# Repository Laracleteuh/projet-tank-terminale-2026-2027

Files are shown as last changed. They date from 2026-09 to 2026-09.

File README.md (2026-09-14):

# projet-tank-terminale-2026-2027 ###

Repo GitHub pour le projet de Tank RC des Terminales spécialités sciences de l'ingénieur. Contenu Open Source, et maintenu jusqu'en juillet 2027

### Configuration Requise ###

Ce projet est basé autour de l'Arduino Mega 2560 programmé via VS Code et son extension PlatformIO.
Sur chaque release un fichier .zip a build et un .hex pouvant être uploadé directement sera disponible.
Le fichier d'environnement platformio.ini est publié dans son dossier /PlatformIO/

### Tank OS ###

La dernière version en date de TankOS est TankOS 1.
[Lien vers la dernière release de TankOS](https://github.com/Laracleteuh/projet-tank-terminale-2026-2027/releases/tag/TankOS1)

*La documentation technique se trouve dans Manuel Utilisateur / Logiciel / TankOS 1.html - .pdf*

### PCB Custom ###

Ce projet contient quelques cartes électroniques faites sur mesure. Les fichiers de celles-ci seront disponibles plus tard dans l'année, quand leur design sera validé et fonctionnel.
Ces designs ont étés fait sur KiCAD.

### Python Scripts ###

Ce projet contient un dossier réservé à des scripts python. Ils sont fait maison et permettent de calculer des caractéristiques en rapport avec les moteurs plus facilement, n'hesitez pas à vous en servir si besoin ;). Pour moins se casser la tête pour des valeurs par défaut, dans la première input, tapez "def" pour charger les valeurs par défaut du programme. Elles seront mises à jour si jamais elles changent au cours du projet.

### MatLab ###

Ce projet contient un dossier réservé aux modèles MatLab et aux calculs. Dans celui-ci vous pourrez trouver le(s) modèle(s) de simulation des moteurs, et la fiche de calcul qui justifie CHAQUE valeur de MatLab (autre que celle qu'on peut trouver dans les docs techniques, vous pouvez chercher quand même, là c'est que les calculs)

### User Manuals ###

Ce projet contient un dossier réservé aux manuels utilisateurs. Ces manuels seront répartis dans des dossiers selon le type d'élément qu'ils présentent (PCB par exemple)

### Feuilles de Calcul ###

Ce projet contient un dossier réservé aux feuilles de calculs pour le tank. Utile si besoin. (Feuilles manuscrites)

### Nom des versions ###

Deux types de firmware sont actuellement utilisés : 
  - Les _PUBLIC_PREVIEW (PR) -> firmware non-testés sur du materiel réel, soumis à des erreurs
  - Les _PUBLIC_RELEASE (REL) -> firmware testé sur du materiel et certifié sans erreur, soumis à des ajouts de fonctionnalité dans le futur

Chaque mise à jour est présentée sous la forme suivante : 20XX.Y_TYPE

20XX -> correspond à l'année d'écriture du firmware

.Y -> correspond à la version du firmware

_TYPE -> soit _PUBLIC_PREVIEW ou _PUBLIC_RELEASE

---
### Licence ###

Ce projet est distribué sous licence MIT pour le code. Les schémas électroniques et fichiers PCB sont mis à disposition sous licence CERN-OHL-P v2.

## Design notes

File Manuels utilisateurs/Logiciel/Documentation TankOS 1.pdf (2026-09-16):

# Documentation TankOS1

### Groupe Spécialité Sciences de l’Ingénieur 16 Septembre 2026

Firmware de contrôle pour plateforme chenillée radiocommandée

Projet Tank Terminale, Spécialité Sciences de l’Ingénieur, session 2026/2027 — Version 1 — Carte cible Arduino Mega 2560 (ATmega2560)

### Sommaire

### Introduction

### 1. Présentation générale

TankOS est le firmware embarqué pilotant une plateforme chenillée radiocommandée à deux moteurs de traction et une tourelle motorisée équipée d’un système d’armement simulé (ESC double). Le firmware est écrit en C++ pour l’environnement Arduino, compilé et déployé via PlatformIO, et s’exécute sur une carte Arduino Mega 2560 basée sur le microcontrôleur ATmega2560 (8 bits, 16 MHz, 8 Ko de SRAM, 256 Ko de mémoire programme).

Le système repose sur un noyau temps réel FreeRTOS (portage AVR de la bibliothèque feilipu/FreeRTOS) et organise le traitement en cinq tâches concurrentes ordonnancées par priorité. Cette architecture remplace une structure séquentielle classique de type loop() et garantit que les fonctions critiques de sécurité (perte de liaison radio, surintensité, décharge batterie) sont exécutées avec une latence bornée, indépendamment de la charge des autres sous-systèmes.

Les fonctions principales assurées par le firmware sont les suivantes :
- Pilotage différentiel de la traction par relais et potentiomètres numériques SPI
- Pilotage de la tourelle : élévation et rotation par servomoteurs, activation de deux contrôleurs de vitesse électroniques (ESC)
- Réception de dix voies de la radiocommande par capture d’impulsions PWM en interruption
- Supervision de deux batteries (châssis et tourelle) et d’un capteur de courant, avec bridage automatique de la vitesse et alertes
- Coupure matérielle de l’alimentation moteur en cas de défaillance (MOSFET de puissance piloté logiciellement)
- Contrôle d’accès par badge RFID pour déverrouiller les commandes sensibles
- Interface de commande textuelle disponible simultanément sur liaison série USB et sur module Bluetooth HM-10
- Régulation thermique par ventilateur piloté en PWM matériel haute fréquence

TankOS 1 — Documentation technique — Projet Tank Terminale, Spécialité SI 2026/2027

### 2. Architecture matérielle

L’ensemble du brochage est centralisé dans le fichier config.h, seul point de référence pour toute modification physique du câblage. Les sous-systèmes matériels sont décrits ci-dessous ; le détail exhaustif des broches figure en annexe.

### 2.1 Chaîne de traction

Chaque moteur de traction est commandé par un ensemble de relais montés sur une carte pilote MDRVCT60A002M. La direction (avant/arrière) de chaque moteur est sélectionnée par une paire de relais dédiés, et deux relais supplémentaires assurent la coupure générale de l’alimentation de chaque côté (fonction de sécurité indépendante de la direction). La vitesse est réglée par un potentiomètre numérique SPI MCP41100 par moteur, adressé par une broche CS dédiée (42 pour le moteur gauche, 43 pour le moteur droit), le bus SPI (SCK/MOSI/MISO sur les broches matérielles 52/51/50) étant partagé avec le lecteur RFID.

### 2.2 Tourelle

La tourelle intègre trois servomoteurs analogiques pour le mouvement d’élévation et la rotation (broches 2, 3 et 6 pilotées en parallèle) et deux ESC pour l’armement (broches 4 et 5, pilotage en largeur d’impulsion de 1000 à 2000 microsecondes).

### 2.3 Réception radiocommande

Une radiocommande de type huit voies transmet des signaux PWM captés par interruption logicielle sur changement d’état (bibliothèque enableInterrupt). Les voies exploitées couvrent la direction et la vitesse de traction, l’orientation et l’élévation de la tourelle, l’armement, la vitesse de rampe (VRB) et deux interrupteurs auxiliaires (SWC, SWD). La capture est réalisée dans ISR.cpp, fichier isolé du reste du firmware car il gère les temporisations critiques en contexte d’interruption.

### 2.4 Lecteur RFID

Le contrôle d’accès admin repose sur un lecteur RC522 en liaison SPI, avec sélection sur la broche 41 et réinitialisation sur la broche 40. Sur Mega, le bus SPI matériel est situé sur les broches 50/51/52 (contrairement à un Uno où il se trouve sur 11/12/13), et des résistances série de 330 ohms sont insérées sur SCK et MOSI pour la compatibilité de niveaux logiques 5V du module.

### 2.5 Liaison Bluetooth

Un module HM-10 est connecté sur Serial1 à 9600 bauds et fournit une interface de commande sans fil identique à la liaison série USB. Une broche BRK (37) permet de forcer une rupture de connexion Bluetooth de façon logicielle.

### 2.6 Capteurs et actionneurs auxiliaires

La température est relevée par un capteur I2C MCP9808. Deux ponts diviseurs analogiques mesurent la tension des batteries châssis (A1) et tourelle (A2), un capteur à effet Hall (type ACS) mesure le courant consommé (A0). Un ventilateur est commandé en modulation de largeur d’impulsion matérielle à 25 kHz par configuration directe du timer 2 (broche 9). Une LED RGB de statut (broches 46 à 49) restitue l’état global du système.

### 2.7 Sécurité matérielle

Un transistor MOSFET canal P (FQP27P06) commandé sur la broche 32 permet la coupure matérielle de l’alimentation de puissance de la chaîne de traction, indépendamment de l’état des relais de direction, en complément de la logique de sécurité logicielle.

### 3. Architecture logicielle et ordonnancement FreeRTOS

Le firmware utilise le portage AVR de FreeRTOS (feilipu/FreeRTOS) afin de garantir un ordonnancement préemptif par priorité. Cinq tâches sont créées au démarrage, chacune encapsulant une boucle infinie rythmée par vTaskDelay(), ce qui libère le processeur pour les tâches de priorité inférieure ou égale pendant l’attente.

Tâche | Priorité | Période | Responsabilité
TaskSafety | 4 (la plus haute) | 20 ms | Détection de perte de liaison radio, calcul du facteur de bridage batterie, coupure de l’alimentation trac-tion, gestion de la LED de statut
TaskTraction | 3 | 34 ms | Lecture des voies radio et application des consignes de vitesse/direction à la chaîne de traction
TaskTourelle | 3 | 34 ms | Élévation, rotation et armement de la tourelle
TaskCommunication | 2 | 20 ms | Traitement des commandes série/Bluetooth, gestion des ventilateurs, télémétrie périodique
TaskAdmin | 1 (la plus basse) | 50 ms | Scrutation du lecteur RFID et gestion du verrouillage admin

La priorité de TaskSafety est volontairement maximale : elle doit pouvoir préempter toute autre tâche afin de garantir la coupure immédiate de la traction et de la tourelle en cas de perte de signal, quelle que soit la charge des autres modules.

### 3.1 Synchronisation par mutex

Deux sémaphores mutex, déclarés globalement dans config.h et instanciés dans main.cpp, protègent les ressources partagées entre tâches :
- spiMutex : protège l’accès exclusif au bus SPI matériel, partagé entre le lecteur RC522 (admin.cpp) et les potentiomètres numériques MCP41100 (traction.cpp). La totalité d’une transaction (sélection du composant, transfert des octets, désélection) est encadrée par la prise et la libération du mutex, afin de garantir son atomicité.
- stateMutex : protège l’état partagé calculé par TaskSafety (indicateur de failsafe actif, facteur de bridage de vitesse)
et consommé par TaskTraction et TaskTourelle.

Les prises de mutex sont systématiquement bornées dans le temps (pdMS_TO_TICKS(5)) : en cas d’indisponibilité, la tâche appelante renonce à l’opération pour le cycle courant plutôt que de bloquer indéfiniment, préservant ainsi le respect des échéances temporelles de l’ordonnanceur.

### 3.2 Communication inter-tâches

Les données de la radiocommande sont exposées par getRecepteurData(), qui recopie sous section critique (taskENTER_CRITICAL() / taskEXIT_CRITICAL()) les variables volatiles renseignées par les routines d’interruption vers une structure RcData locale à chaque tâche appelante. Cette structure regroupe les huit canaux : axes de traction, axes de tourelle, interrupteurs SWC/SWD, potentiomètres VRA/VRB.

### 3.3 Point d’entrée et supervision

La fonction setup() initialise séquentiellement chaque module matériel, crée les mutex, instancie les cinq tâches via xTaskCreate() en vérifiant systématiquement leur code de retour, puis démarre l’ordonnanceur via vTaskStartScheduler(). La fonction loop() Arduino reste vide, le contrôle étant entièrement cédé au noyau FreeRTOS. Un hook vApplicationStackOverflowHook() est enregistré pour signaler sur le port série tout dépassement de pile d’une tâche et figer volontairement le système, ce comportement étant préférable à une corruption mémoire silencieuse.

### 4. Module Traction

Le module traction.cpp implémente une machine à états par moteur (structure Motor), avec trois états : IDLE (moteur arrêté), RUNNING (moteur en mouvement dans une direction donnée) et SWITCHING (phase transitoire lors d’une inversion de direction). Un changement direct de sens de marche sans passage par un arrêt intermédiaire de 200 millisecondes est proscrit afin de protéger l’électronique de puissance et les moteurs des courants d’appel liés à une inversion brutale.

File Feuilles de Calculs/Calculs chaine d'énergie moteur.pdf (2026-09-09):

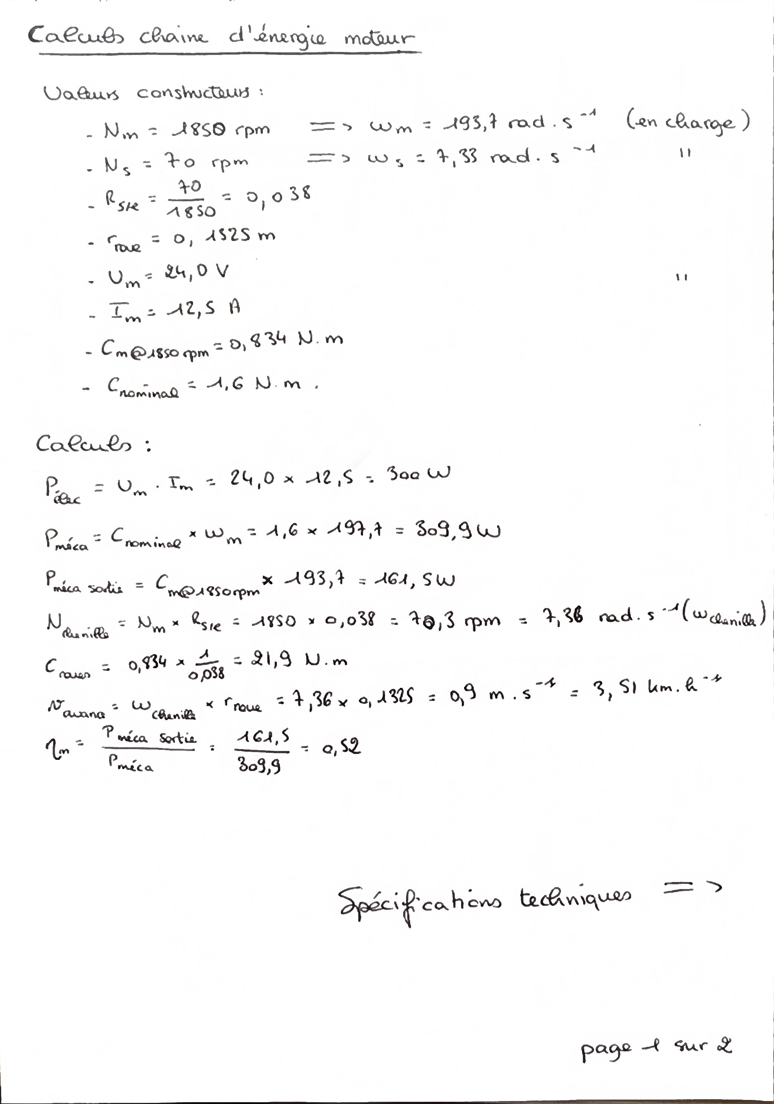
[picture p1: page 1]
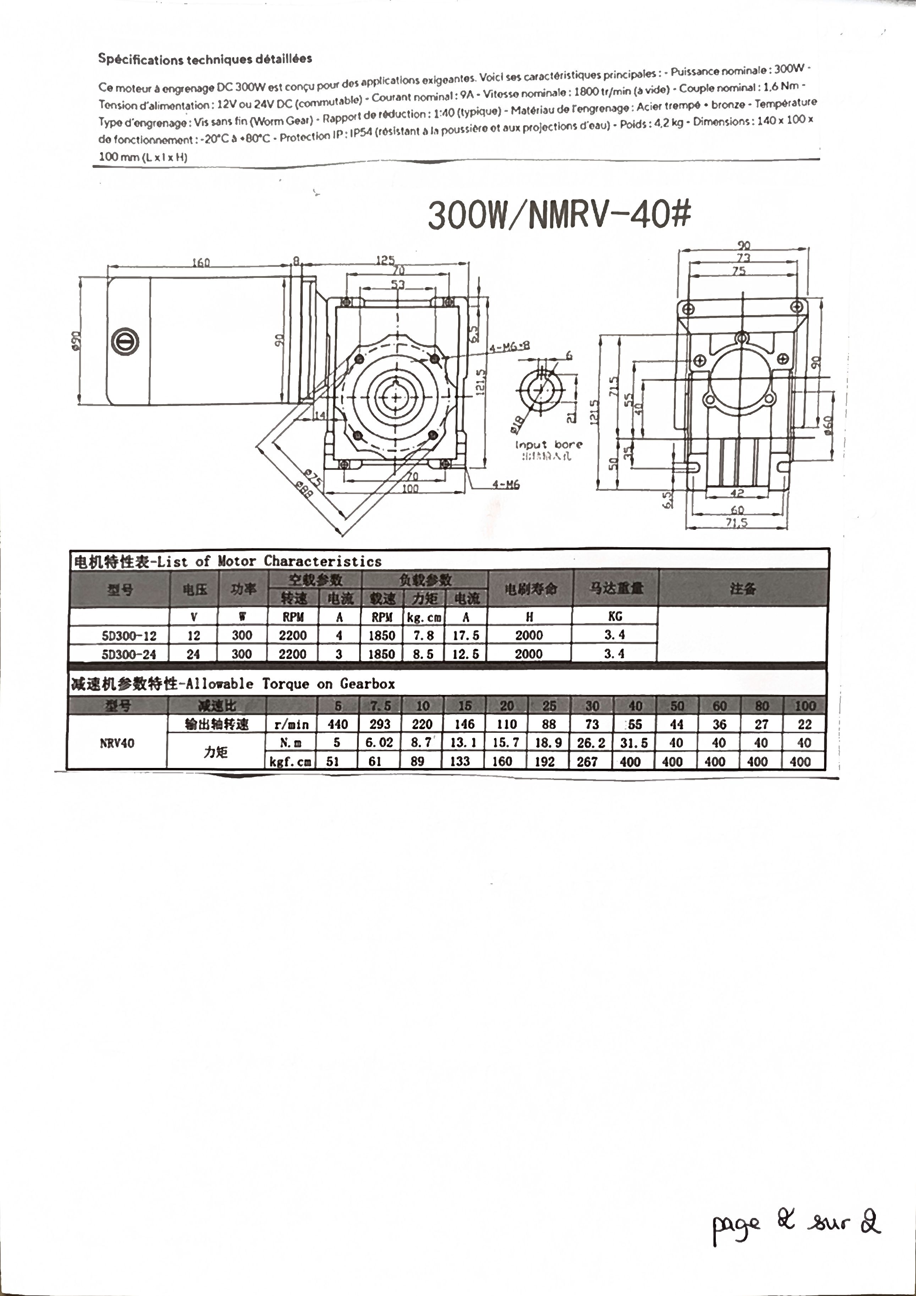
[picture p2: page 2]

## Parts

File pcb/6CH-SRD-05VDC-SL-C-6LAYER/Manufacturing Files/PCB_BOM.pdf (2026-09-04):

# Bill of Materials (BOM)

### Custom PCB Manufacturing Documentation

Reference | Qty | Value | DNP | Exclude from BOM | Exclude from Board | Footprint | Datasheet | Mouser Reference
C1,C2,C3,C4,C5 | 5 | T356M107K020AT | | | | Capacitor_THT:CP_Radial_Tantal_D10.5mm_P5.0 0mm | View PDF (https://eu.mouser.com/datasheet/3/72/1/T356M107K020AT.pdf) | 80-T356M107K020AT
D1,D2,D3,D4,D5,D6 | 6 | 1N4007 | | | | Diode_THT:D_DO-41_SOD81_P10.16mm_Horizon tal | View PDF (http://www.vishay.com/docs/88503/1n4001.pdf) | 637-1N4007
D9,D10,D11 | 3 | 109113 | | | | LED_THT:LED_D3.0mm | View PDF (https://www.mouser.com/catalog/specsheets/liteon_LTW-420D7.pdf) | 859-LTW-420D7
J1 | 1 | S3B-EH(LF)(SN) | | | | Connector_JST:JST_EH_S3B-EH_1x03_P2.50mm_Horizontal | View PDF (https://eu.mouser.com/datasheet/3/1070/1/eEH.pdf) | 306-S3B-EHLFSN
J2 | 1 | S5B-EH(LF)(SN) | | | | Connector_JST:JST_EH_S5B-EH_1x05_P2.50mm_Horizontal | View PDF (https://eu.mouser.com/datasheet/3/1070/1/eEH.pdf) | 306-S5B-EHLFSN
J11,J12 | 2 | S6B-EH(LF)(SN) | | | | Connector_JST:JST_EH_S6B-EH_1x06_P2.50mm_Horizontal | View PDF (https://eu.mouser.com/datasheet/3/1070/1/eEH.pdf) | 306-S6B-EHLFSN
K1,K2,K3,K4,K5,K6 | 6 | 101287 | | | | USER_FOOTPRINT:RELAY_SRD-05VDC-SL-C | - | 392-101287
Q1 | 1 | FQP27P06 | | | | Package_TO_SOT_THT:TO-220-3_Horizontal_Tab Down | View PDF (https://www.onsemi.com/pub/Collateral/FQP27P06-D.PDF) | 512-FQP27P06
R1,R2,R4 | 3 | MF0204FTE52-220 R | | | | Resistor_THT:R_Axial_DIN0204_L3.6mm_D1.6mm _P5.08mm_Horizontal | View PDF (https://eu.mouser.com/datasheet/3/508/1/YAGEO_MF0_DATASHEET.pdf) | 603-MF0204FTE52-220 R
R3 | 1 | MF0204FTE52-1K | | | | _P5.08mm_Horizontal Resistor_THT:R_Axial_DIN0204_L3.6mm_D1.6mm | View PDF (https://eu.mouser.com/datasheet/3/508/1/YAGEO_MF0_DATASHEET.pdf) | 603-MF0204FTE52-1K

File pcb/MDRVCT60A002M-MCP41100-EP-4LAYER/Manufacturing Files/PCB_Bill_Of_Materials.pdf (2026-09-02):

# Bill of Materials (BOM)

PCB Production Export

Reference | Qty | Value | Footprint | Mouser Part No. | Datasheet
C1,C2 | 2 | C320C104M5R5TA7301 | USER_FOOTPRINT:C320C104M5R5TA7301 | 80-C320C104M5R7301 | Datasheet Link (https://www.yageogroup.com/content/datasheet/asset/file/KEM_C1050_GOLDMAX_X7R)
C3,C4,C5,C6 | 4 | T356M107K020AT | Capacitor_THT:CP_Radial_Tantal_D10.5mm_P5.0 0mm | 80-T356M107K020AT | Datasheet Link (https://eu.mouser.com/datasheet/3/72/1/T356M107K020AT.pdf)
D1,D2,D3,D4,D5,D6 | 6 | 1N4007 | Diode_THT:D_DO-41_SOD81_P10.16mm_Horizo ntal | 637-1N4007 | Datasheet Link (http://www.vishay.com/docs/88503/1n4001.pdf)
D7,D8,D9,D10,D11, D12,D13,D14 | 8 | LTW-420D7 | LED_THT:LED_D3.0mm_Clear | 859-LTW-420D7 | Datasheet Link (https://www.mouser.com/catalog/specsheets/liteon_LTW-420D7.pdf)
IC1,IC2 | 2 | MCP41100-E_P | USER_FOOTPRINT:DIP765W56P254L946H432Q 8N | 579-MCP41100-E/P | Datasheet Link (https://ww1.microchip.com/downloads/aemDocuments/documents/OTH/ProductDocuments/DataSheets/11195c.pdf)
J1,J2 | 2 | S4B-EH(LF)(SN) | Connector_JST:JST_EH_S4B-EH_1x04_P2.50mm_Horizontal | 306-S4B-EHLFSN | Datasheet Link (https://eu.mouser.com/datasheet/3/1070/1/eEH.pdf)
J3,J4 | 2 | S3B-EH(LF)(SN) | Connector_JST:JST_EH_S3B-EH_1x03_P2.50mm_Horizontal | 306-S3B-EHLFSN | Datasheet Link (https://eu.mouser.com/datasheet/3/1070/1/eEH.pdf)
J8,J9 | 2 | TB0013-500-P05GR | TerminalBlock:TerminalBlock_MaiXu_MX126-5.0-0 5P_1x05_P5.00mm | 179-TB0013-500-P05GR | Datasheet Link (https://www.sameskydevices.com/product/resource/tb0013-500.pdf)
J11 | 1 | S6B-EH(LF)(SN) | Connector_JST:JST_EH_S6B-EH_1x06_P2.50mm_Horizontal | 306-S6B-EHLFSN | Datasheet Link (https://eu.mouser.com/datasheet/3/1070/1/eEH.pdf)
K1,K2,K3,K4,K5,K6 | 6 | 101287 | USER_FOOTPRINT:RELAY_SRD-05VDC-SL-C | 392-101287 | -
Q7 | 1 | FQP27P06 | Package_TO_SOT_THT:TO-220-3_Horizontal_Tab Down | 512-FQP27P06 | Datasheet Link (https://www.onsemi.com/pdf/datasheet/fqp27p06-d.pdf)
Q8,Q9,Q10,Q11,Q1 2,Q13 | 6 | 2N2219 | Package_TO_SOT_THT:TO-39-3 | 494-2N2219 | Datasheet Link (http://www.onsemi.com/pub_link/Collateral/2N2219-D.PDF)
R1,R2,R3,R4,R15,R 16,R17,R19 | 8 | MF0204FTE52-220R | Resistor_THT:R_Axial_DIN0204_L3.6mm_D1.6m m_P5.08mm_Horizontal | 603-MF0204FTE52-220R | Datasheet Link (https://eu.mouser.com/datasheet/3/508/1/YAGEO_MF0_DATASHEET.pdf)
R5,R6,R7,R8,R9,R1 0,R11,R12 | 8 | MF0204FTE52-1K | Resistor_THT:R_Axial_DIN0204_L3.6mm_D1.6m m_P5.08mm_Horizontal | 603-MF0204FTE52-1K | Datasheet Link (https://eu.mouser.com/datasheet/3/508/1/YAGEO_MF0_DATASHEET.pdf)
R13,R14,R18,R20,R 21,R22,R23,R24,R2 5 | 9 | MF0204FTE52-10K | Resistor_THT:R_Axial_DIN0204_L3.6mm_D1.6m m_P5.08mm_Horizontal | 603-MF0204FTE52-10K | Datasheet Link (https://eu.mouser.com/datasheet/3/508/1/YAGEO_MF0_DATASHEET.pdf)

Reference | Qty | Value | Footprint | Mouser Part No. | Datasheet
TP1 | 1 | GND | TestPoint:TestPoint_Pad_D1.5mm | - | -
TP2 | 1 | 5V | TestPoint:TestPoint_Pad_D1.5mm | - | -
TP3 | 1 | RELAYS_VCC | TestPoint:TestPoint_Pad_D1.5mm | - | -
TP4,TP9 | 2 | L1 | TestPoint:TestPoint_Pad_D1.5mm | - | -
TP5 | 1 | W1 | TestPoint:TestPoint_Pad_D1.5mm | - | -
TP6 | 1 | H1 | TestPoint:TestPoint_Pad_D1.5mm | - | -
TP7 | 1 | W2 | TestPoint:TestPoint_Pad_D1.5mm | - | -
TP8 | 1 | H2 | TestPoint:TestPoint_Pad_D1.5mm | - | -
TP10 | 1 | TPR1 | TestPoint:TestPoint_Pad_D1.5mm | - | -
TP11 | 1 | TPR2 | TestPoint:TestPoint_Pad_D1.5mm | - | -
TP12 | 1 | TPR3 | TestPoint:TestPoint_Pad_D1.5mm | - | -
TP13 | 1 | TPR4 | TestPoint:TestPoint_Pad_D1.5mm | - | -
TP14 | 1 | TPR5 | TestPoint:TestPoint_Pad_D1.5mm | - | -
TP15 | 1 | TPR6 | TestPoint:TestPoint_Pad_D1.5mm | - | -

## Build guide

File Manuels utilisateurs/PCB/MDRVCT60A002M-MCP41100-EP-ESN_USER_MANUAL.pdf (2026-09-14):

# User Manual

Motor Driver Controller MDRVCT60A002M-MCP41100-EP/ESN REV : SEPT 2026

By Groupe Spé SI Terminale

Contents :

I – Introduction | . | p3
II – Technical Specifications | | p4
- Electrical Specifications | .. | p4
-Dimensions | | p4
III – Installation and Wiring | | p5
- Power Input | | p5
- Arduino Wiring | | p5-6
- Driver wiring | | p7-8
- Status LED Reading | | p8
IV – Code example | | p10
V – File Preview | | p13
- Full PCB Layout (EP/ESN) | p13-14 / 15-16
- Full 3D Render (EP/ESN) | p14 / 16
- Schematic | | p17-18

I – Introduction
The MDRVCT60A002M-MCP41100-EP/ESN is a motor driver controller that is made for this specific 60A motor driver (https://fr.aliexpress.com/item/1005009146752470.html?curPageLogUid=59CINCWiGLfn) :

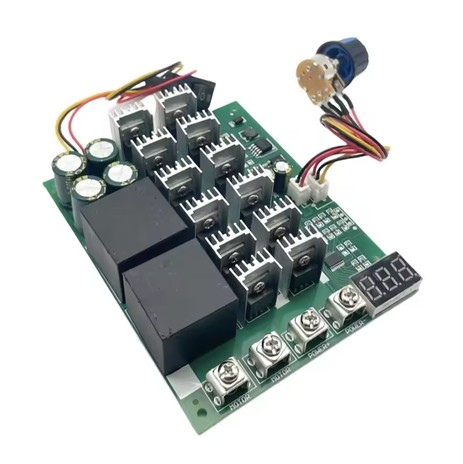
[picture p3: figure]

It is made to replace the manual potentiometer and button so that an Arduino can pilot it. You can then integrate it in application such as RC Tank which relies on heavy motors. It works by replacing the manual potentiometer via a MCP41100, its click button and the other button via relays. Two versions exists as of this day :
- The MCP41100-EP as its PDIP interface is really easy to solder by hand.
- The MCP41100-ESN as its SOP-8 interface was easier to found online, yet is still relatively easy to solder
The PCB is publicly available but you will need to manufacture it and assemble it by yourself. The BOM will be in the corresponding GitHub release next to the PCB files.

This product is designed in a way it can pilot two of those drivers. If you only want to use one driver with it, just wire the Arduino to one MCP41100-EP and three Relays. A more detailed schematic will be available below.

[GitHub link to the MDRVCT60A002M-MCP41100-EP release] (https://github.com/Laracleteuh/projet-tank-terminale-2026-2027/releases/tag/MDRVCT60A002M-MCP41100-EP) [GitHub link to the MDRVCT60A002M-MCP41100-ESN release] (https://github.com/Laracleteuh/projet-tank-terminale-2026-2027/releases/tag/MDRVCT60A002M-MCP41100-ESN)

II – Technical Specification
a. Electrical Specifications
This board is made to function on 5V only, please do not input anything above or below 5V, you could fry the MCP41100-EP / ESN. If you aren’t confident about your 5V input, feel free to use a LM2596 module set to 5V in order to provide a clean 5V output to the board.
The MCP41100-EP /ESN works via a SPI input interface, and its output are like a normal potentiometer (High, Low, Wiper).
When you are using it, please be sure to connect a ground that goes to your power source, and one that goes to the Arduino you are using.
b. Schematic & Dimensions
- Dimensions of the board :

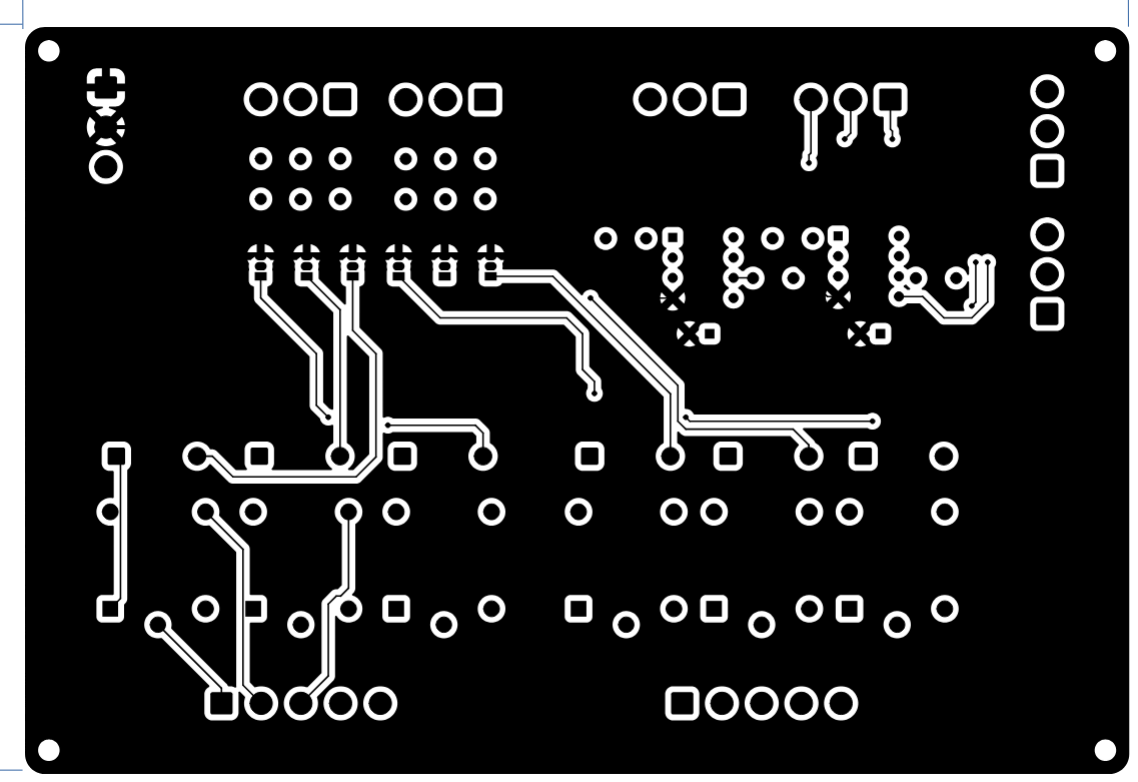
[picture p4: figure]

At each corner there is a mouting hole, which is an M2 mounting hole, and is placed 3.5mm away from the edges of the PCB.

Please refer to the last two pages to read the schematic
Note : There isn’t any difference in the wiring between the MCP41100-EP and -ESN, the only thing that is different is the footprint used. The placement of the nearby resistors and capacitor may differ. Please choose the version of the board that suits you the best, and the componant you can find online.

140 mm

9

5

m

m

III – Installation and wiring
- Power Input
The power goes through this JST-EH connector :

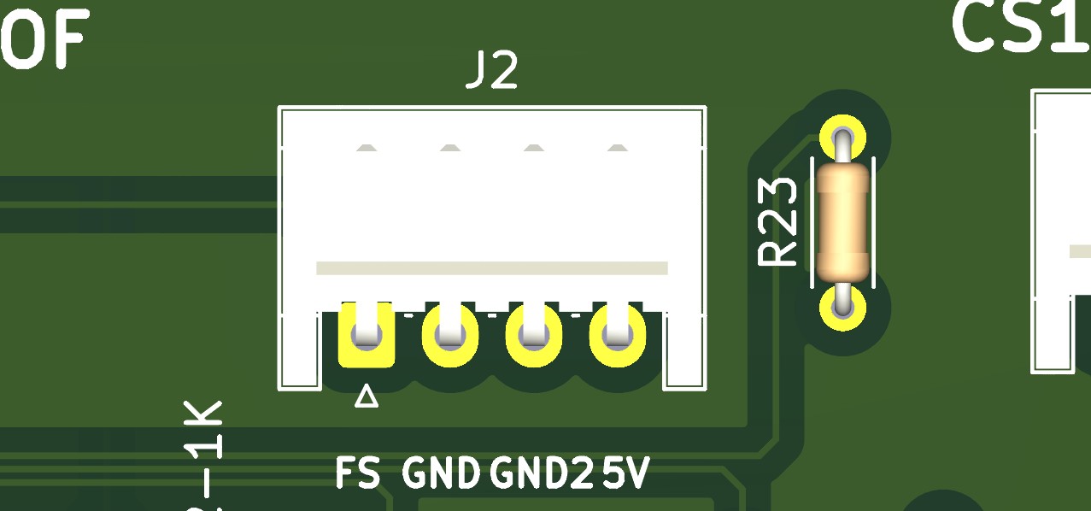
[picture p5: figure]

From left to right pin : Failsafe (FS), GND, GND2, 5V
The 5V pin needs to be wired to a reliable power source, allowing at least 1A of current to be drawn from. Therefore the 5V Arduino PIN isn’t suitable to power this board.
The GND pin is the ground that needs to return to the power source.
The GND2 pin needs to be wired to the micro-controller that controls the relays and the ICs.
The Failsafe pin needs to be wired to an Arduino pin which is set on LOW at all times. When the arduino loses power or disconnects, it cuts power to all relays.
- Arduino wiring
You need an Arduino, or any microcontroller that has GPIO pins and support SPI communication. Before choosing any MCU, please verify if it has enough pins to control the board (at least 11 standard I/O pins + GND).
The board is linked to the arduino via one 6-pin connector and one 4-pin connector. The first one controls all six relays while the other one controls both MCP41100s. Both connector are JST-EH type connectors. Please refer to the BOM at the end of the manual to have the full reference of the connectors. As IC1 & IC2 communicate via SPI protocol, please be sure your microcontroller has SPI pins available. For Arduino Mega, those pins are on 52 for SCK and 51 for SI (MOSI).

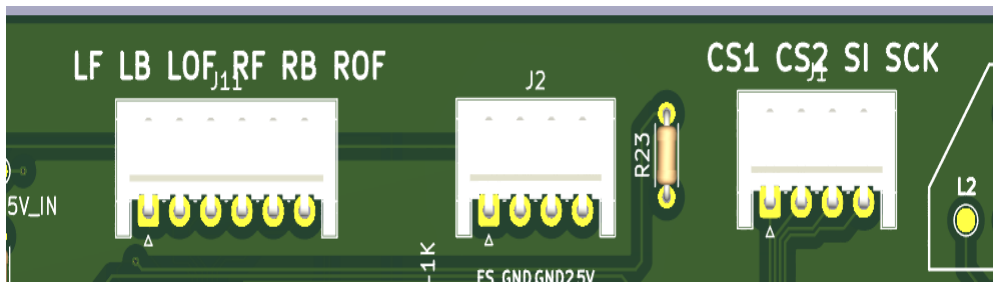
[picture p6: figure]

On the board is written what each pin controls, allowing easier testing. Both connectors are located next to each other.
Translation of each abbreviation :
- L(R)F : Left (Right) Motor, Forward Direction. Put HIGH or LOW to enable or disable the relay.
- L(R)B : Left (Right) Motor, Backward Direction. Put HIGH or LOW to enable or disable the relay.
- L(R)OF : Left (Right) Motor, On Off Control. Put HIGH or LOW to enable or disable the relay.
- CS1 : Chip Select 1, for IC1. Put LOW to enable the chip to receive information through the SI bus.
- CS2 : Chip Select 2, for IC2. Put LOW to enable the chip to receive information through the SI bus.
- SI : Signal bus sending data to either IC1 or IC2 (MOSI). Send digital data (from 0 to 255) to control the output’s resistance.
- SCK : Clock signal, operated by the microcontroller automatically.

- Driver wiring
As this board can control two drivers at the same time, there is sixteen pins on the board to send information to the drivers. But if you want to control one driver, you only need eight pins of the board.
There is two types of connector on the board that communicate to the driver :
- Screw Terminals :

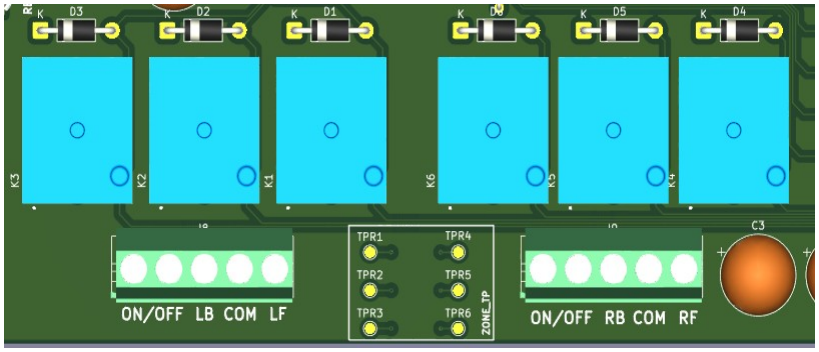
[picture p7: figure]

As you can see there is two 1x05 pin screw terminal. One for each driver. Explanation for the left terminal from right to left :
- 1st and 2nd pin (ON/OFF) : Left Motor On/Off control (replaces the click of the potentiometer).
- 3rd pin (LB) : Left Motor Backward Direction (replaces one of the three state button input)
- 4th pin (COM) : Left Motor three state button common pin
- 5th pin (LF) : Left Motor Forward Direction (replace ones of the three state button input)

The same logic applies to the right terminal, but for the right motor.

- JST-EH Type Connectors :

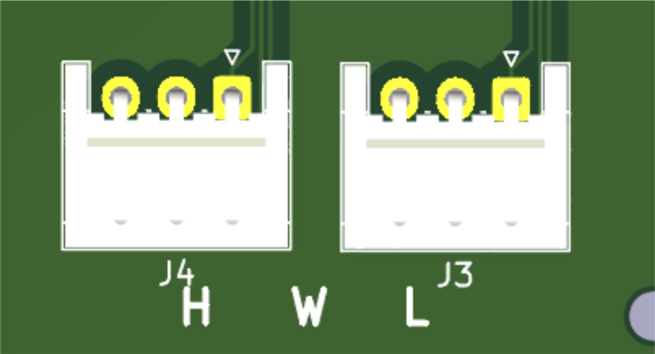
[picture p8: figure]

Then there is two 3-pins EH-Type connectors. They are used as a replacement to the manual potentiometer. There is one connector for each driver. And both work the same (from left to right) :
- L : Low Terminal
- W : Wiper Pin
- H : High Terminal
- Status LEDs Reading
There are 8 LEDs that act as status indication of the board.
The first set of LEDs is located on the left of the board and the LEDs are labeled « PWR » and « REL » :

The « PWR » LED indicates whether the board is electrically powered

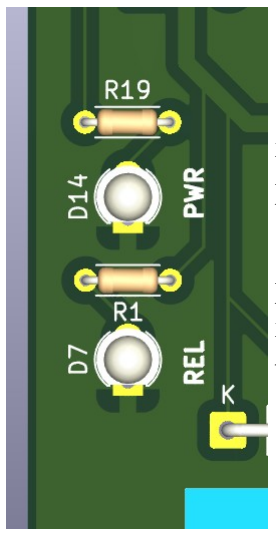
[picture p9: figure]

or not, even if the Microcontroller is unresponsive or don’t send any information through the communication ports, it will be on as long as power is connected to the board.
The « REL » LED indicates whether all 6 relays are connected to power or not. It is connected to the failsafe MOSFET and will be on if power is allowed to go through the relays, meaning that the FS pin is set LOW by the microcontroller.

The second set of LEDs is located on the down-right of the board, and the LEDs are labeled « LOF », « LB », « LF », « ROF », « RB » and « RF ». Each of these is connected to one relay and is on if the relay is set open, if any of them is off, it means that no current is applied to the relay, therefore the relay is closed.

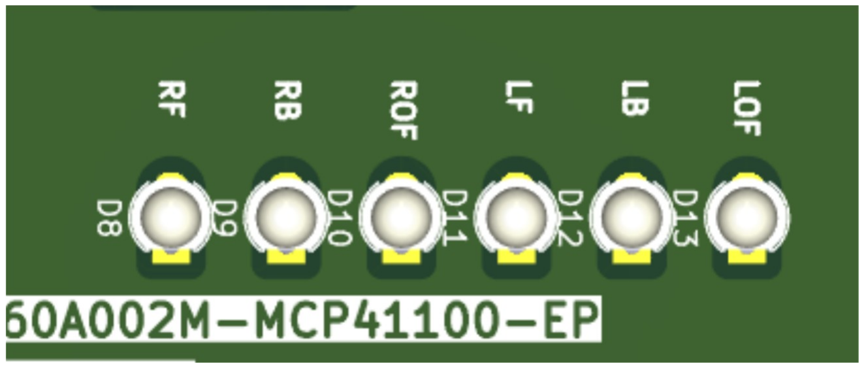
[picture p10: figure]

IV – Code example
This code applies to an RC Tank, and is therefore controlling two drivers via the MDRVCT60A002M-MCP41100-EP/ESN, and via an RC controller. However it isn’t optimised, it is just an example about the board works.

#include <Arduino.h>

#include <SPI.h>

// ==========================================

// 1. PIN DEFINITIONS

// ==========================================

// RC Controller Input Pins

#define speedPin A9

#define steeringPin A8

// Left Motor Relays

#define leftMotorFwd 22

#define leftMotorBck 23

#define leftMotorPower 26

// Right Motor Relays

#define rightMotorFwd 24

#define rightMotorBck 25

#define rightMotorPower 27

// Digital Potentiometer SPI Pins (Chip Select)

#define leftPotCS 42

#define rightPotCS 43

// Relay logic (Low-level trigger)

#define RELAY_ON LOW

#define RELAY_OFF HIGH

// ==========================================

// 2. SET MOTOR POWER

// ==========================================

// This function sends a raw value (0 to 255) to the digital

// potentiometer via SPI to control the motor controller's throttle.

void setMotorSpeed(int csPin, int speedValue) {
digitalWrite(csPin, LOW); | // Select the specific potentiometer
SPI.transfer(0x11); | // Send the "Write Data" command
SPI.transfer(speedValue); | // Send the speed level (0 to 255)

digitalWrite(csPin, HIGH); // Deselect the potentiometer
}

// ==========================================

// 3. SETUP: INITIALIZE PINS & SPI

// ==========================================

void setup() {
pinMode(speedPin, INPUT);

pinMode(steeringPin, INPUT);

pinMode(leftMotorFwd, OUTPUT);

pinMode(leftMotorBck, OUTPUT);

pinMode(leftMotorPower, OUTPUT);

pinMode(rightMotorFwd, OUTPUT);

pinMode(rightMotorBck, OUTPUT);

pinMode(rightMotorPower, OUTPUT);

digitalWrite(leftMotorFwd, RELAY_OFF);

digitalWrite(leftMotorBck, RELAY_OFF);

digitalWrite(rightMotorFwd, RELAY_OFF);

digitalWrite(rightMotorBck, RELAY_OFF);

digitalWrite(leftMotorPower, RELAY_ON);

digitalWrite(rightMotorPower, RELAY_ON);

pinMode(leftPotCS, OUTPUT);

pinMode(rightPotCS, OUTPUT);

digitalWrite(leftPotCS, HIGH);

digitalWrite(rightPotCS, HIGH);

SPI.begin();
}

// ==========================================

// 4. MAIN LOOP: READ & DRIVE

// ==========================================

void loop() {
// A standard RC signal is between 980 (min) and 2000 (max), with ~1500 being the center.

int rawSpeed = pulseIn(speedPin, HIGH);

int rawSteering = pulseIn(steeringPin, HIGH);

int speedPercentage = 0;

int steeringPercentage = 0;

// Deadzone if (abs(rawSpeed - 1500) > 50) {

speedPercentage = map(rawSpeed, 980, 2000, -100, 100); }

if (abs(rawSteering - 1500) > 50) {

steeringPercentage = map(rawSteering, 980, 2000, -100, 100); }

// Differential Steering

int leftSpeed = speedPercentage;

int rightSpeed = speedPercentage;

if (steeringPercentage > 0) { // Turning Right

leftSpeed = speedPercentage + steeringPercentage;

rightSpeed = speedPercentage - steeringPercentage;
} else if (steeringPercentage < 0) { // Turning Left

leftSpeed = speedPercentage - abs(steeringPercentage);

rightSpeed = speedPercentage + abs(steeringPercentage); }

leftSpeed = constrain(leftSpeed, -100, 100);

rightSpeed = constrain(rightSpeed, -100, 100);

if (leftSpeed > 0) {

digitalWrite(leftMotorFwd, RELAY_ON);

digitalWrite(leftMotorBck, RELAY_OFF);

} else if (leftSpeed < 0) {

digitalWrite(leftMotorFwd, RELAY_OFF);

digitalWrite(leftMotorBck, RELAY_ON);

} else {

digitalWrite(leftMotorFwd, RELAY_OFF);

digitalWrite(leftMotorBck, RELAY_OFF); }

// Convert 0-100% to 0-255 for the SPI chip

setMotorSpeed(leftPotCS, map(abs(leftSpeed), 0, 100, 0, 255));

if (rightSpeed > 0) {

digitalWrite(rightMotorFwd, RELAY_ON);

digitalWrite(rightMotorBck, RELAY_OFF);

} else if (rightSpeed < 0) {

digitalWrite(rightMotorFwd, RELAY_OFF);

digitalWrite(rightMotorBck, RELAY_ON);

} else {

digitalWrite(rightMotorFwd, RELAY_OFF);

digitalWrite(rightMotorBck, RELAY_OFF);
}

setMotorSpeed(rightPotCS, map(abs(rightSpeed), 0, 100, 0, 255));

// Delay to prevent destructive relay switching

delay(200); }

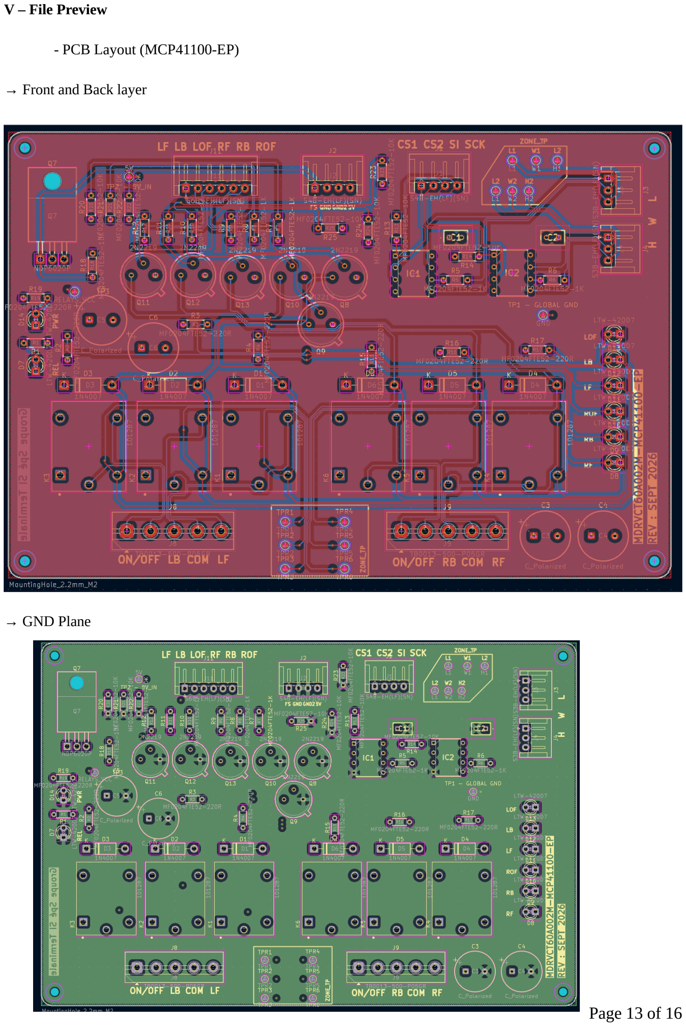
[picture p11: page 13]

V – File Preview

- PCB Layout (MCP41100-EP)

→ Front and Back layer

→ GND Plane

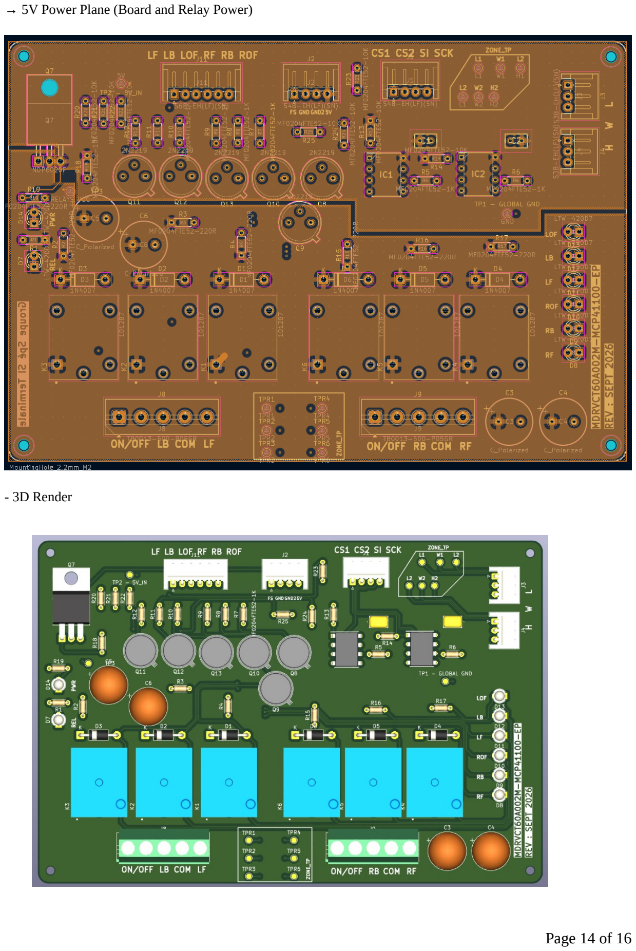
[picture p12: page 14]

→ 5V Power Plane (Board and Relay Power)

- 3D Render

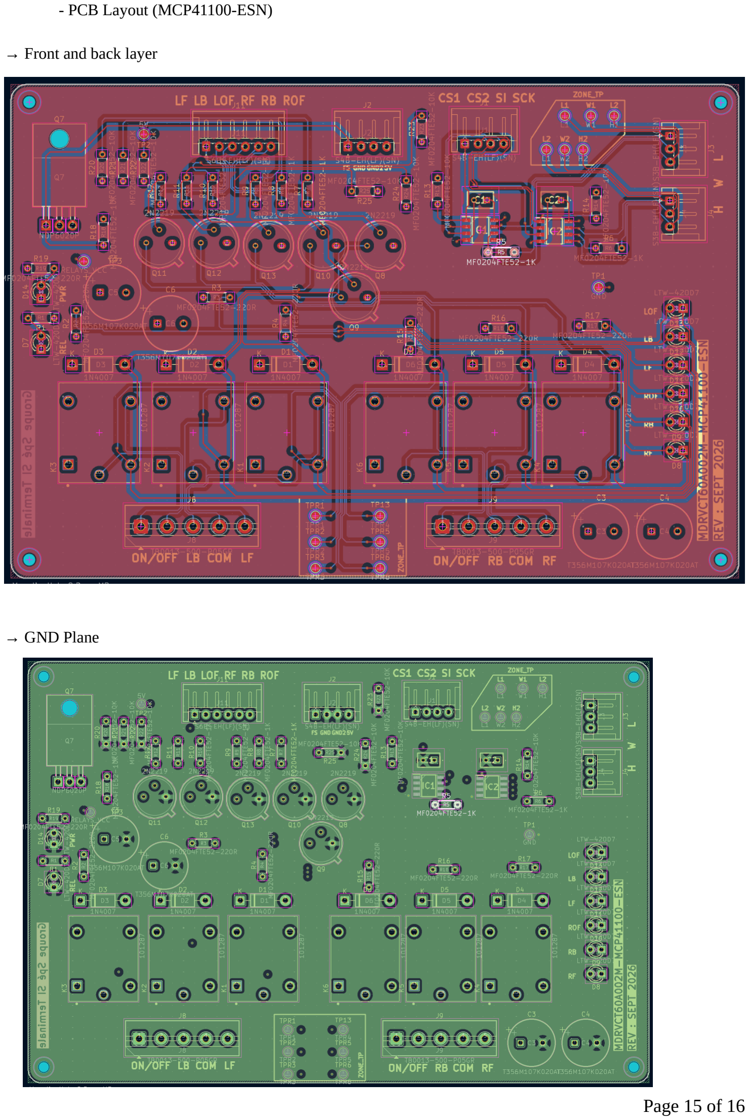
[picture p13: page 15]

- PCB Layout (MCP41100-ESN)

→ Front and back layer

→ GND Plane

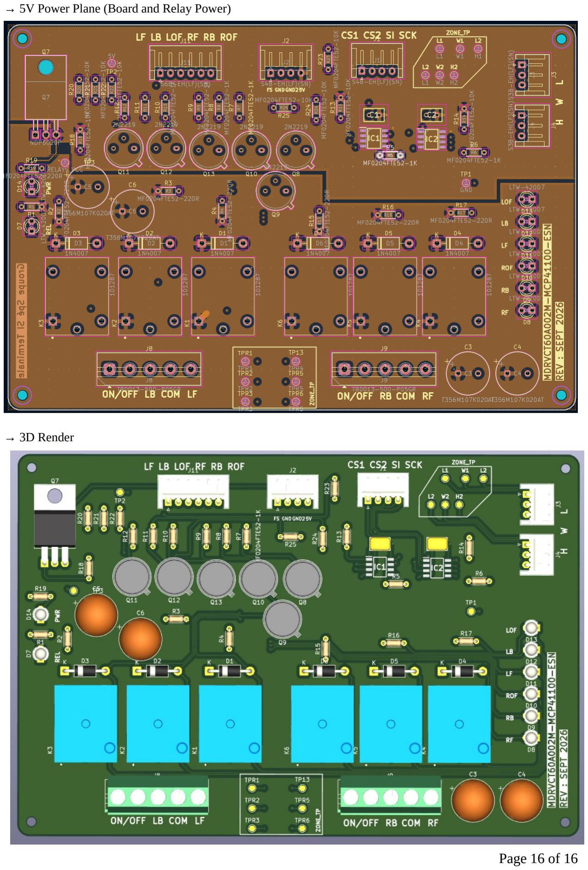
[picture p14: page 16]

→ 5V Power Plane (Board and Relay Power)

→ 3D Render

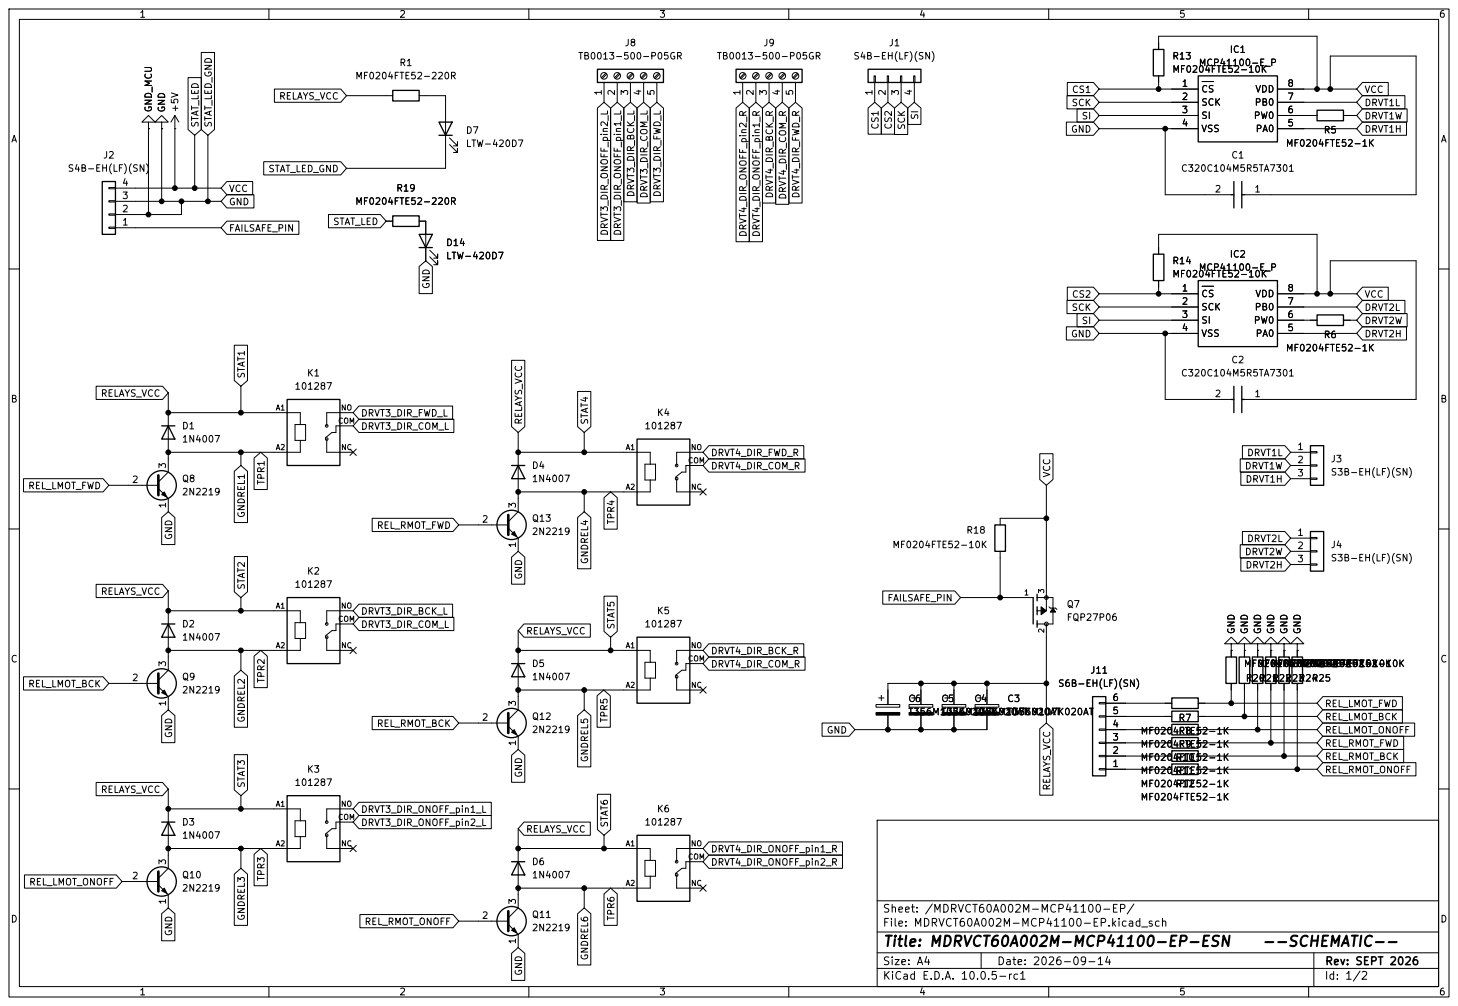
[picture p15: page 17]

# LTW-420D7 D11

STAT1 | GNDREL4 | GNDREL2 DRVT1L | DRVT1W | DRVT1H | DRVT2W | TPR5 | TPR6

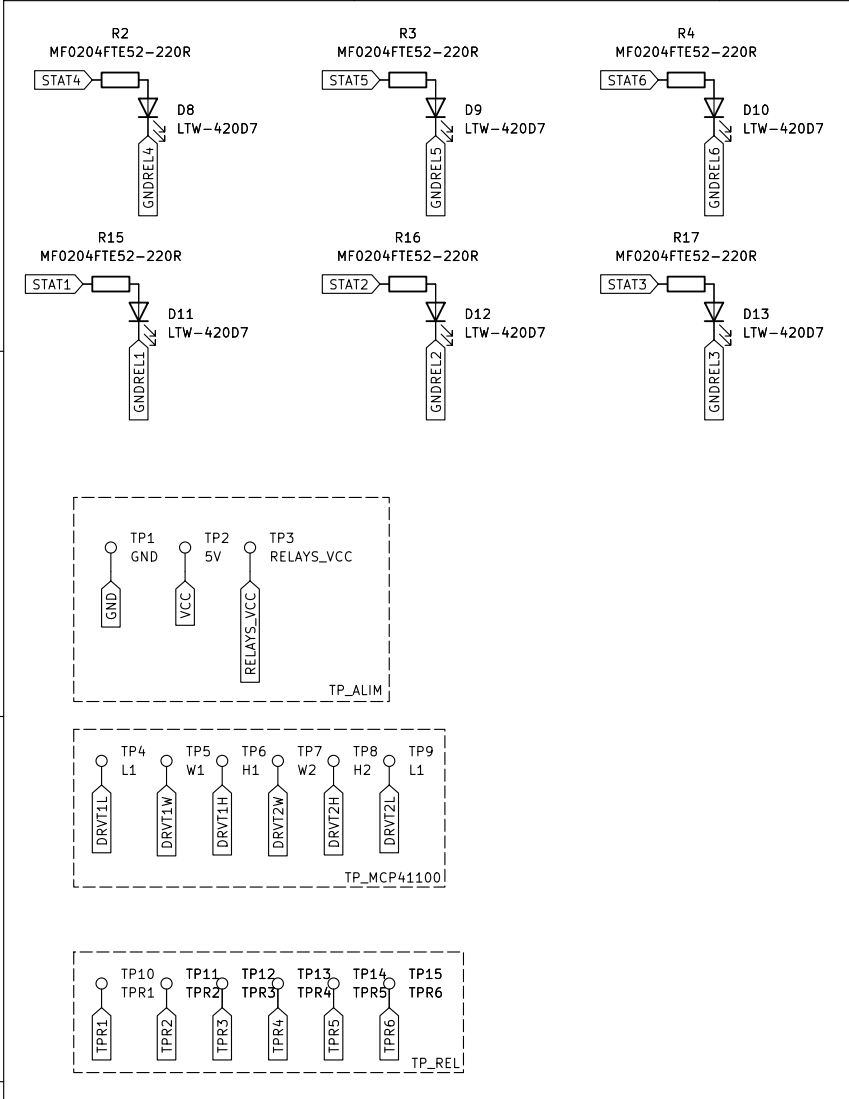
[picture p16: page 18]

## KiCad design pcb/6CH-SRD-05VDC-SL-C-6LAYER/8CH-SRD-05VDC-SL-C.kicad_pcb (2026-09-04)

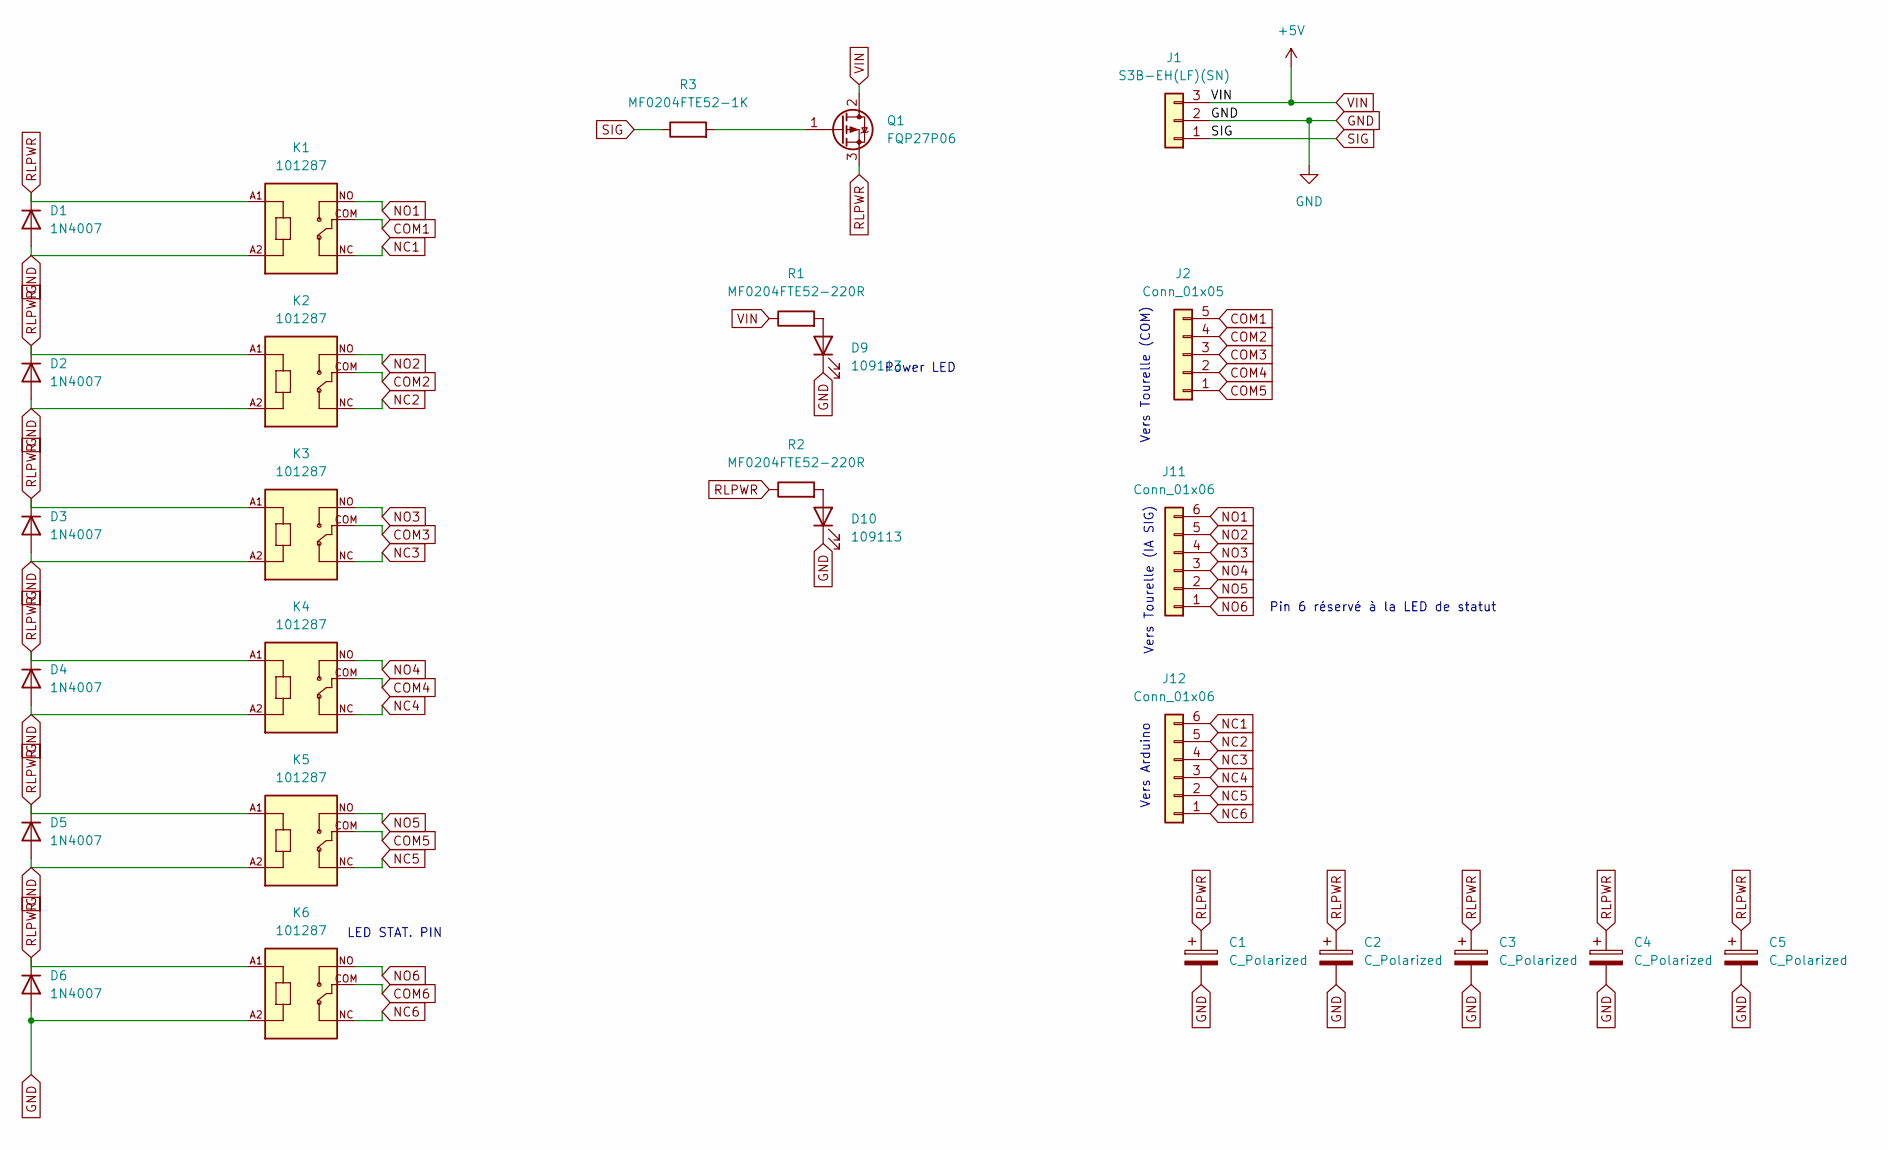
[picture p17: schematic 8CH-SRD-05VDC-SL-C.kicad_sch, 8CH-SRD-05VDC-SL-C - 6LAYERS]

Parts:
C1, C2, C3, C4, C5: C_Polarized; CP_Radial_Tantal_D10.5mm_P5.00mm
D1, D2, D3, D4, D5, D6: 1N4007; D_DO-41_SOD81_P10.16mm_Horizontal; Mouser Reference 637-1N4007
D9, D10: 109113; LED_D3.0mm; Mouser Reference 859-LTW-420D7
J1: S3B-EH(LF)(SN); JST_EH_S3B-EH_1x03_P2.50mm_Horizontal; Mouser Reference 306-S3B-EHLFSN
J2: Conn_01x05; JST_EH_S5B-EH_1x05_P2.50mm_Horizontal
J11, J12: Conn_01x06; JST_EH_S6B-EH_1x06_P2.50mm_Horizontal
K1, K2, K3, K4, K5, K6: 101287; RELAY_SRD-05VDC-SL-C; Mouser Reference 392-101287
Q1: FQP27P06; TO-220-3_Horizontal_TabDown
R1, R2: MF0204FTE52-220R; R_Axial_DIN0204_L3.6mm_D1.6mm_P5.08mm_Horizontal; Mouser Reference 603-MF0204FTE52-220R
R3: MF0204FTE52-1K; R_Axial_DIN0204_L3.6mm_D1.6mm_P5.08mm_Horizontal

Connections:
COM1: J2.5, K1.COM
COM2: J2.4, K2.COM
COM3: J2.3, K3.COM
COM4: J2.2, K4.COM
COM5: J2.1, K5.COM
COM6: K6.COM
GND: C1.2, C2.2, C3.2, C4.2, C5.2, D1.2 (A), D2.2 (A), D3.2 (A), D4.2 (A), D5.2 (A), D6.2 (A), D9.1 (K), D10.1 (K), J1.2, K1.A2, K2.A2, K3.A2, K4.A2, K5.A2, K6.A2; also elsewhere on the board
NC1: J12.6, K1.NC
NC2: J12.5, K2.NC
NC3: J12.4, K3.NC
NC4: J12.3, K4.NC
NC5: J12.2, K5.NC
NC6: J12.1, K6.NC
NO1: J11.6, K1.NO
NO2: J11.5, K2.NO
NO3: J11.4, K3.NO
NO4: J11.3, K4.NO
NO5: J11.2, K5.NO
NO6: J11.1, K6.NO; also elsewhere on the board
unnamed: D9.2 (A), R1.2
unnamed: D10.2 (A), R2.2
unnamed: Q1.1 (G), R3.2
RLPWR: C1.1, C2.1, C3.1, C4.1, C5.1, D1.1 (K), D2.1 (K), D3.1 (K), D4.1 (K), D5.1 (K), D6.1 (K), K1.A1, K2.A1, K3.A1, K4.A1, K5.A1, K6.A1, Q1.3 (S), R2.1
SIG: J1.1, R3.1
VIN: J1.3, Q1.2 (D), R1.1

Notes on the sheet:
LED STAT. PIN
Pin 6 réservé à la LED de statut
Vers Tourelle (COM)
Power LED
Vers Tourelle (IA SIG)
Vers Arduino

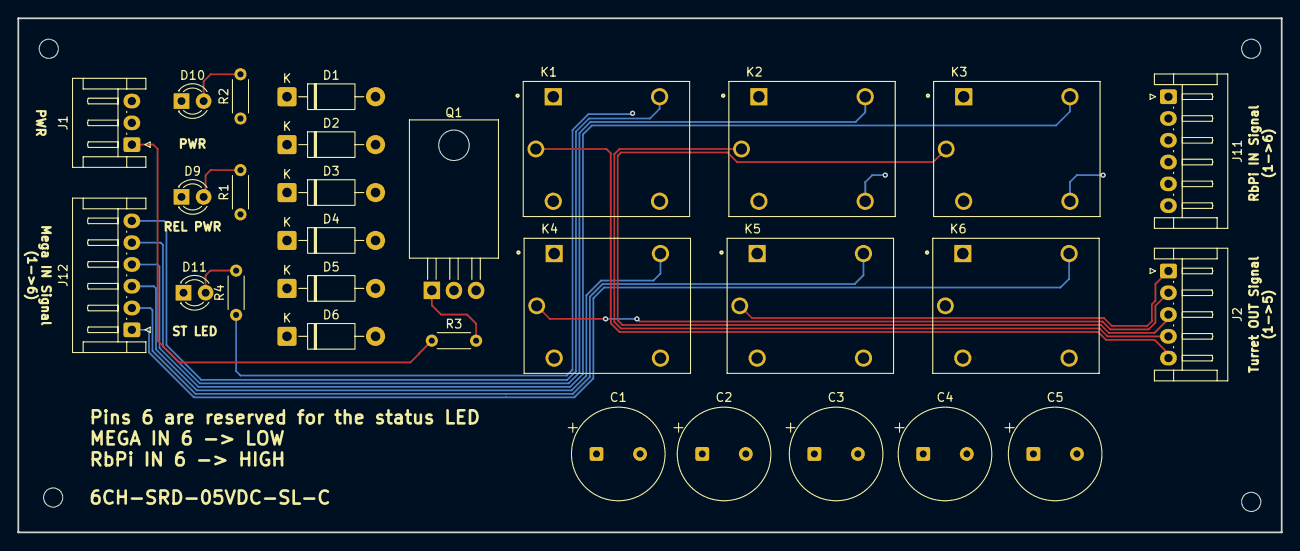
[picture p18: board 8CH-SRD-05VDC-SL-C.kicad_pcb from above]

Board: 6 copper layers, 145.0 x 59.0 mm, 29 parts (0 on the bottom side), 25 nets.

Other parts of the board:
D11: 109113; LED_D3.0mm
R4: MF0204FTE52-220R; R_Axial_DIN0204_L3.6mm_D1.6mm_P5.08mm_Horizontal

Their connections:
GND: D11.1 (K); also elsewhere on the board
NO6: R4.1; also elsewhere on the board
unnamed: D11.2 (A), R4.2

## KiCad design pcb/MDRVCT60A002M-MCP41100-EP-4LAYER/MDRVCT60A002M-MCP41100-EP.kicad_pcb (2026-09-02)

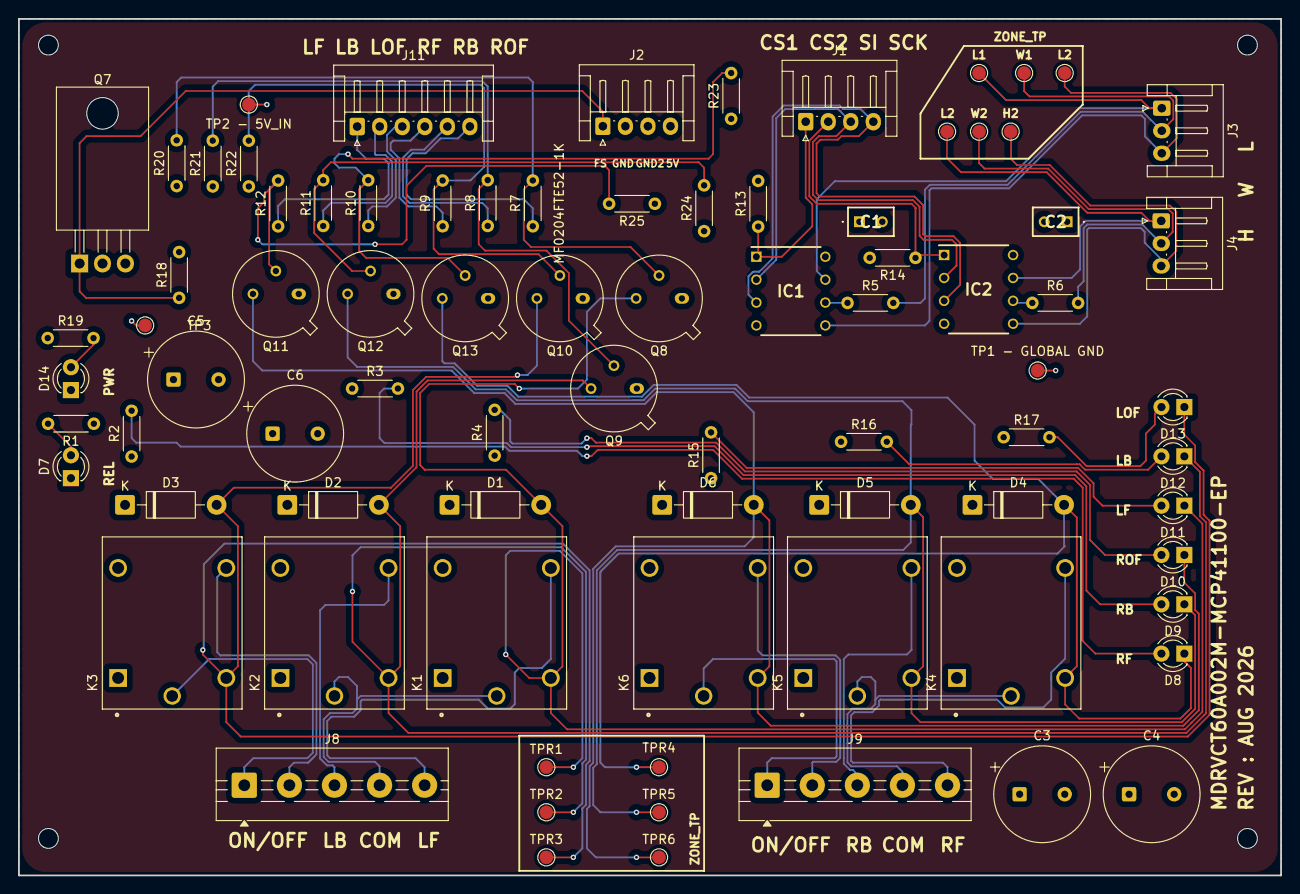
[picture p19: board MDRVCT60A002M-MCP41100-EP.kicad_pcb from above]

Board: 4 copper layers, 140.0 x 95.0 mm, 86 parts (0 on the bottom side), 52 nets.

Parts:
 : MountingHole_2.2mm_M2
  : MountingHole_2.2mm_M2
 #2,  #3: MountingHole_2.2mm_M2
C1, C2: C320C104M5R5TA7301
C3, C4, C5, C6: C_Polarized; CP_Radial_Tantal_D10.5mm_P5.00mm
D1, D2, D3, D4, D5, D6: 1N4007; D_DO-41_SOD81_P10.16mm_Horizontal
D7, D8, D9, D10, D11, D12, D13, D14: LTW-420D7; LED_D3.0mm_Clear
IC1, IC2: MCP41100-E_P; DIP765W56P254L946H432Q8N
J1, J2: S4B-EH(LF)(SN); JST_EH_S4B-EH_1x04_P2.50mm_Horizontal
J3, J4: S3B-EH(LF)(SN); JST_EH_S3B-EH_1x03_P2.50mm_Horizontal
J8, J9: TB0013-500-P05GR; TerminalBlock_MaiXu_MX126-5.0-05P_1x05_P5.00mm
J11: S6B-EH(LF)(SN); JST_EH_S6B-EH_1x06_P2.50mm_Horizontal
K1, K2, K3, K4, K5, K6: 101287; RELAY_SRD-05VDC-SL-C
Q7: NDP6020P; TO-220-3_Horizontal_TabDown
Q8, Q9, Q10, Q11, Q12, Q13: 2N2219; TO-39-3
R1, R2, R3, R4, R15, R16, R17, R19: MF0204FTE52-220R; R_Axial_DIN0204_L3.6mm_D1.6mm_P5.08mm_Horizontal
R5, R6, R7, R8, R9, R10, R11, R12: MF0204FTE52-1K; R_Axial_DIN0204_L3.6mm_D1.6mm_P5.08mm_Horizontal
R13, R14, R18, R20, R21, R22, R23, R24, R25: MF0204FTE52-10K; R_Axial_DIN0204_L3.6mm_D1.6mm_P5.08mm_Horizontal
TP1 - GLOBAL GND: GND; TestPoint_Pad_D1.5mm
TP2 - 5V_IN: 5V; TestPoint_Pad_D1.5mm
TP3: RELAYS_VCC; TestPoint_Pad_D1.5mm
TP4, TP9: L1; TestPoint_Pad_D1.5mm
TP5: W1; TestPoint_Pad_D1.5mm
TP6: H1; TestPoint_Pad_D1.5mm
TP7: W2; TestPoint_Pad_D1.5mm
TP8: H2; TestPoint_Pad_D1.5mm
TP10: TPR1; TestPoint_Pad_D1.5mm
TP11: TPR2; TestPoint_Pad_D1.5mm
TP12: TPR3; TestPoint_Pad_D1.5mm
TP14: TPR5; TestPoint_Pad_D1.5mm
TP15: TPR6; TestPoint_Pad_D1.5mm
TPR4: TPR4; TestPoint_Pad_D1.5mm

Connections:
CS1: IC1.1 (~CS), J1.1, R13.1
CS2: IC2.1 (~CS), J1.2, R14.1
DRVT1H: IC1.5 (PA0), J3.3, TP6.1 (1_1)
DRVT1L: IC1.7 (PB0), J3.1, TP4.1 (1_1)
DRVT1W: J3.2, R5.2, TP5.1 (1_1)
DRVT2H: IC2.5 (PA0), J4.3, TP8.1 (1_1)
DRVT2L: IC2.7 (PB0), J4.1, TP9.1 (1_1)
DRVT2W: J4.2, R6.2, TP7.1 (1_1)
DRVT3_DIR_BCK_L: J8.3, K2.NO
DRVT3_DIR_COM_L: J8.4, K1.COM, K2.COM
DRVT3_DIR_FWD_L: J8.5, K1.NO
DRVT3_DIR_ONOFF_pin1_L: J8.2, K3.NO
DRVT3_DIR_ONOFF_pin2_L: J8.1, K3.COM
DRVT4_DIR_BCK_R: J9.3, K5.NO
DRVT4_DIR_COM_R: J9.4, K4.COM, K5.COM
DRVT4_DIR_FWD_R: J9.5, K4.NO
DRVT4_DIR_ONOFF_pin1_R: J9.2, K6.NO
DRVT4_DIR_ONOFF_pin2_R: J9.1, K6.COM
FAILSAFE_PIN: J2.1, Q7.1, R18.1
GND: C1.2, C2.2, C3.2, C4.2, C5.2, C6.2, D7.1 (K), D14.1 (K), IC1.4 (VSS), IC2.4 (VSS), J2.2, J2.3, Q8.1 (E), Q9.1 (E), Q10.1 (E), Q11.1 (E), Q12.1 (E), Q13.1 (E), R20.1, R21.1, R22.1, R23.1, R24.1, R25.1, TP1 - GLOBAL GND.1 (1_1)
GNDREL1: D1.2 (A), D11.1 (K), K1.A2, Q8.3 (C), TP10.1 (1_1)
GNDREL2: D2.2 (A), D12.1 (K), K2.A2, Q9.3 (C), TP11.1 (1_1)
GNDREL3: D3.2 (A), D13.1 (K), K3.A2, Q10.3 (C), TP12.1 (1_1)
GNDREL4: D4.2 (A), D8.1 (K), K4.A2, Q13.3 (C), TPR4.1 (1_1)
GNDREL5: D5.2 (A), D9.1 (K), K5.A2, Q12.3 (C), TP14.1 (1_1)
GNDREL6: D6.2 (A), D10.1 (K), K6.A2, Q11.3 (C), TP15.1 (1_1)
unnamed: D7.2 (A), R1.2
unnamed: D8.2 (A), R2.2
unnamed: D9.2 (A), R3.2
unnamed: D10.2 (A), R4.2
unnamed: D11.2 (A), R15.2
unnamed: D12.2 (A), R16.2
unnamed: D13.2 (A), R17.2
unnamed: D14.2 (A), R19.2
unnamed: IC1.6 (PW0), R5.1
unnamed: IC2.6 (PW0), R6.1
unnamed: J11.1, R12.1
unnamed: J11.2, R11.1
unnamed: J11.3, R10.1
unnamed: J11.4, R9.1
unnamed: J11.5, R8.1
unnamed: J11.6, R7.1
RELAYS_VCC: C3.1, C4.1, C5.1, C6.1, D1.1 (K), D2.1 (K), D3.1 (K), D4.1 (K), D5.1 (K), D6.1 (K), K1.A1, K2.A1, K3.A1, K4.A1, K5.A1, K6.A1, Q7.2, R1.1, R2.1, R3.1, R4.1, R15.1, R16.1, R17.1, TP3.1 (1_1)
REL_LMOT_BCK: Q9.2 (B), R8.2, R21.2
REL_LMOT_FWD: Q8.2 (B), R7.2, R20.2
REL_LMOT_ONOFF: Q10.2 (B), R9.2, R22.2
REL_RMOT_BCK: Q12.2 (B), R11.2, R24.2
REL_RMOT_FWD: Q13.2 (B), R10.2, R23.2
REL_RMOT_ONOFF: Q11.2 (B), R12.2, R25.2
SCK: IC1.2 (SCK), IC2.2 (SCK), J1.3
SI: IC1.3 (SI), IC2.3 (SI), J1.4
STAT_LED: C1.1, C2.1, IC1.8 (VDD), IC2.8 (VDD), J2.4, Q7.3, R13.2, R14.2, R18.2, R19.1, TP2 - 5V_IN.1 (1_1)

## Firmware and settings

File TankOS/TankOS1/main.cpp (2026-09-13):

// =============================================================================================
// Programme Projet Tank Terminale - Spé SI
// Version : TankOS 1 (Basé sur FreeRTOS pour microcontrôleur AVR)
// Révision : 13 Septembre 2026
// Carte : Arduino Mega 2560
// Baudrate : 115200
// =============================================================================================

#include <Arduino.h>
#include <Arduino_FreeRTOS.h>
#include <semphr.h>
#include <avr/wdt.h>

// ==============================================================================
// S'exécute matériellement AVANT le démarrage du framework Arduino.
// Il garantit que le Watchdog est neutralisé dès la mise sous tension.
// ==============================================================================
#ifdef __cplusplus
extern "C" {
#endif

void wdt_init(void) __attribute__((naked, used, section(".init3")));

void wdt_init(void) {
    MCUSR = 0;       // Etape 1 OBLIGATOIRE : Effacer le drapeau de reset
    wdt_disable();   // Etape 2 : Désactiver le chien de garde
} // <--- PREMIÈRE ACCOLADE ICI : Elle ferme la fonction wdt_init

#ifdef __cplusplus
} // <--- SECONDE ACCOLADE ICI : Elle ferme le bloc "extern C"
#endif 

#include "Config.h"
#include "Systeme.h"
#include "Traction.h"
#include "Tourelle.h"
#include "ISR.h"
#include "communication.h"
#include "batterie.h"
#include "Securite.h"
#include "admin.h"

// -- Définition des handles/mutex déclarés extern dans Config.h --
TaskHandle_t hTaskSafety = NULL;
TaskHandle_t hTaskTraction = NULL;
TaskHandle_t hTaskTourelle = NULL;
TaskHandle_t hTaskCommunication = NULL;
TaskHandle_t hTaskAdmin = NULL;

SemaphoreHandle_t spiMutex = NULL;
SemaphoreHandle_t stateMutex = NULL;
SemaphoreHandle_t serialMutex = NULL;

// -- État partagé, calculé par TaskSafety et consommé par TaskTraction/TaskTourelle --
static volatile bool  g_failsafeActive = true;
static volatile float g_safetyFactor   = 0.0f;

void TaskSafety(void *pvParameters) {
  (void)pvParameters;

  for (;;) {
    bool failsafe = checkFailsafe();
    int mainPct = getBatteryPercentage(MAIN_BATTERY_PIN);
    float amps = getCurrentAmps();

    float battSafety = calculerBridageBatterie(mainPct);
    float currentSafety = calculerBridageCourant(amps);
    float safety = min(battSafety, currentSafety);

    if (xSemaphoreTake(stateMutex, pdMS_TO_TICKS(5)) == pdTRUE) {
      g_failsafeActive = failsafe;
      g_safetyFactor = safety;
      xSemaphoreGive(stateMutex);
    }

    if (failsafe) {
      stopTraction();
      stopTourelle();
      setTractionPowerSwitch(false);
      setStatusColor(255, 255, 0);
    } else {
      setTractionPowerSwitch(true);
      int turretPct = getBatteryPercentage(TURRET_BATTERY_PIN);
      gererAlertesBatterie(mainPct, turretPct, amps);
    }

    vTaskDelay(pdMS_TO_TICKS(20));
  }
}

void TaskTraction(void *pvParameters) {
  (void)pvParameters;

  for (;;) {
    RcData rc = getRecepteurData();

    bool failsafe = true;
    float safetyFactor = 0.0f;
    
    if (xSemaphoreTake(stateMutex, pdMS_TO_TICKS(5)) == pdTRUE) {
      failsafe = g_failsafeActive;
      safetyFactor = g_safetyFactor;
      xSemaphoreGive(stateMutex);
    }

    int speed = 0;
    int steering = 0;

    if (!failsafe) {
      float userMaxSpeed = getBluetoothSpeedLimit();
      float totalFactor = safetyFactor * userMaxSpeed;
      speed = rcToSpeed(rc.yRaw) * totalFactor;
      steering = rcToSpeed(rc.xRaw) * totalFactor;
    }

    updateTraction(speed, steering, rc.vrbRaw);

    vTaskDelay(pdMS_TO_TICKS(34));
  }
}

void TaskTourelle(void *pvParameters) {
  (void)pvParameters;

  for (;;) {
    RcData rc = getRecepteurData();

    bool failsafe = true;
    if (xSemaphoreTake(stateMutex, pdMS_TO_TICKS(5)) == pdTRUE) {
      failsafe = g_failsafeActive;
      xSemaphoreGive(stateMutex);
    }

    if (!failsafe) {
      updateSwitch(rc.swcRaw);
      updateEscPower(rc.vraRaw);
      updateTourelleElevation(rc.turretY);

      int tSpeed = 0;
      if (rc.turretX > 900) {
        tSpeed = rcToSpeed(rc.turretX);
      }
      updateTourelleRotation(tSpeed);
    }

    vTaskDelay(pdMS_TO_TICKS(34));
  }
}

void TaskCommunication(void *pvParameters) {
  (void)pvParameters;

  for (;;) {
    RcData rc = getRecepteurData();
    updateCommunication(rc.swdRaw);

    vTaskDelay(pdMS_TO_TICKS(20));
  }
}

void TaskAdmin(void *pvParameters) {
  (void)pvParameters;

  for (;;) {
    updateAdmin();
    vTaskDelay(pdMS_TO_TICKS(50));
  }
}

extern "C" void vApplicationStackOverflowHook(TaskHandle_t xTask, char *pcTaskName) {
  Serial.print(F("E0STACK - overflow tache: "));
  Serial.println(pcTaskName);
  Serial.flush();
  while (1) {}
}

void setup() {

  _delay_ms(1500);
  Serial.begin(115200);
  
  // Utilisation de F() pour ne pas surcharger la RAM
  Serial.print(F("Demarrage de "));
  Serial.println(F(FIRMWARE_VERSION));
  Serial.print(F("Last build : "));
  Serial.println(F(LAST_BUILD_DATE));
  Serial.print(F("Auteur : "));
  Serial.println(F(FIRMWARE_AUTHOR));
  
  initStatusLED();
  setStatusColor(255, 0, 0);
  _delay_ms(500);
  
  Serial.println(F("Initialisation des modules..."));

  setupCommunication();
  setupBatterie();
  setupAdmin();

  setStatusColor(0, 0, 255);

  setupSysteme();
  setupTraction();

  pinMode(MDRVCT_FAILSAFE, OUTPUT);
  digitalWrite(MDRVCT_FAILSAFE, LOW);

  setupTourelle();
  setupRecepteur();

  spiMutex = xSemaphoreCreateMutex();
  stateMutex = xSemaphoreCreateMutex();
  serialMutex = xSemaphoreCreateMutex();

  if (spiMutex == NULL || stateMutex == NULL || serialMutex == NULL) {
    Serial.println(F("E0RTOS - echec creation des mutex. Arret."));
    while (1) {}
  }

  BaseType_t okCommunication = xTaskCreate(TaskCommunication, "Communication", STACK_COMMUNICATION, NULL, PRIO_COMMUNICATION, &hTaskCommunication);
  BaseType_t okSafety = xTaskCreate(TaskSafety, "Safety", STACK_SAFETY, NULL, PRIO_SAFETY, &hTaskSafety);
  BaseType_t okTraction = xTaskCreate(TaskTraction, "Traction", STACK_TRACTION, NULL, PRIO_TRACTION, &hTaskTraction);
  BaseType_t okTourelle = xTaskCreate(TaskTourelle, "Tourelle", STACK_TOURELLE, NULL, PRIO_TOURELLE, &hTaskTourelle);
  BaseType_t okAdmin = xTaskCreate(TaskAdmin, "Admin", STACK_ADMIN, NULL, PRIO_ADMIN, &hTaskAdmin);

  if (okCommunication != pdPASS || okSafety != pdPASS || okTraction != pdPASS ||
      okTourelle != pdPASS || okAdmin != pdPASS) {
    Serial.print(F("E0RTOS - echec creation tache(s) : "));
    if (okCommunication != pdPASS) Serial.print(F("Communication "));
    if (okSafety != pdPASS) Serial.print(F("Safety "));
    if (okTraction != pdPASS) Serial.print(F("Traction "));
    if (okTourelle != pdPASS) Serial.print(F("Tourelle "));
    if (okAdmin != pdPASS) Serial.print(F("Admin "));
    Serial.println();
    while (1) {}
  }
  
  _delay_ms(500);

  tareCurrentSensor();
  
  setStatusColor(0, 255, 0);
  Serial.println(F("Initialisation terminee. Demarrage du scheduler FreeRTOS"));

  markSetupComplete();

  vTaskStartScheduler();

  Serial.println(F("E0RTOS - echec demarrage du scheduler."));
  while (1) {}
}

void loop() {
  // Vide
}

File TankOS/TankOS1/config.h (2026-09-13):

#pragma once
#include <Arduino.h>
#include <Arduino_FreeRTOS.h>
#include <semphr.h>

// -- Firmware information --
#define FIRMWARE_VERSION "TankOS 1 (Basé sur FreeRTOS pour microcontrôleur AVR"
#define LAST_BUILD_DATE "13.09.2026"
#define FIRMWARE_AUTHOR "Projet Tank Terminale - Specialite SI 2026 - 2027"

// -- RELAY STATE MACROS --
#define RELAY_ON HIGH
#define RELAY_OFF LOW

// Fonction utilitaire pour tous les relais
inline void relayWrite(int pin, bool state) {
  digitalWrite(pin, state ? RELAY_ON : RELAY_OFF);
}

// -- MOTOR SETUP (Traction) --
#define leftMotorFwdRelay 22
#define leftMotorBckRelay 23
#define rightMotorFwdRelay 24
#define rightMotorBckRelay 25
#define leftMotorOnOffSwitch 26
#define rightMotorOnOffSwitch 27

// -- MCP41100 SETUP (SPI) --
// SCK est matériellement sur la broche 52 de l'Arduino Mega
// SI (MOSI) est matériellement sur la broche 51 de l'Arduino Mega
#define CS_PIN1 42
#define CS_PIN2 43

// -- F-10A SETUP --
#define rightJoystickX A8
#define rightJoystickY A9
#define leftJoystickX A10
#define leftJoystickY A11

#define SWA_PIN 44
#define SWB_PIN 10
#define SWC_PIN 11
#define SWD_PIN 12
#define VRA_PIN 13
#define VRB_PIN 45

// -- TOURELLE & ARMEMENT --
#define switchPIN 31
#define servo1Tourelle 2
#define servo2Tourelle 3
#define esc1Tourelle 4
#define esc2Tourelle 5

// -- TOURELLE : L298N (Rotation X) --
#define motorDriverIN1 6
#define motorDriverIN2 7
#define motorDriverENA 8

// -- CAPTEURS ET VENTILATEURS --
#define fanPWMPin 9

// -- STATUS LEDS --
#define RStatusLED 49
#define GStatusLED 47
#define BStatusLED 46
#define TurretControlStatusLED 48

// -- MDRVCT FAILSAFE --
#define MDRVCT_FAILSAFE 32

// --HM-10 BLUETOOTH MODULE--
#define BT_SERIAL Serial1
#define BT_BRK_PIN 37

// -- LECTEUR RFID ADMIN (RC522, SPI, partage le bus SPI0 avec les MCP41010
// de Traction.cpp : SCK=52, MOSI=51, MISO=50, déjà initialisés ailleurs) --
#define RFID_SS_PIN 41
#define RFID_RST_PIN 40

// -- BATTERY & CURRENT SENSORS --
#define MAIN_BATTERY_PIN A1    // Batterie Châssis (Traction)
#define TURRET_BATTERY_PIN A2  // Batterie Tourelle (Armement/Servos)
#define CURRENT_SENSOR_PIN A0  // Capteur de courant

#define LOW_BATTERY_THRESHOLD_PCT 15
#define OVERCURRENT_THRESHOLD_AMPS 20.0f
#define ALERT_REPEAT_INTERVAL_MS 3000

// -- RC VARIABLES --
const int rxMin = 980;
const int rxMax = 2000;
const int rxCenter = 1500;
const int deadzone = 50;

// Fonction utilitaire pour la conversion RC
inline int rcToSpeed(int rawValue) {
  if (abs(rawValue - rxCenter) < deadzone) {
    return 0;
  }
  int speed = map(rawValue, rxMin, rxMax, -100, 100);
  return constrain(speed, -100, 100);
}

// =============================================================================================
// FREERTOS — PRIORITÉS DES TÂCHES
//
// Plus le nombre est élevé, plus la priorité est haute (idle = 0).
// TaskSafety doit toujours pouvoir préempter tout le reste : c'est elle qui
// coupe traction/tourelle en cas de perte de signal radio.
// =============================================================================================
#define PRIO_SAFETY 4   // Failsafe RC + bridage batterie + LED status
#define PRIO_TRACTION 3   // Lecture RC + updateTraction()
#define PRIO_TOURELLE 3   // Lecture RC + contrôle tourelle/ESC
#define PRIO_COMMUNICATION 2   // BT/Série + ventilos + télémétrie
#define PRIO_ADMIN 1   // Scan RFID (basse fréquence, basse priorité)

// -- Tailles de pile --
// IMPORTANT (port AVR) : ces valeurs sont en MOTS (16 bits), pas en octets.
// Une pile de 128 = 256 octets réels. À ajuster avec
// uxTaskGetStackHighWaterMark() une fois le firmware qui tourne.
#define STACK_SAFETY        300
#define STACK_TRACTION      300
#define STACK_TOURELLE      300
#define STACK_COMMUNICATION 400
#define STACK_ADMIN         300

// -- Handles de tâches (définis dans main.cpp) --
extern TaskHandle_t hTaskSafety;
extern TaskHandle_t hTaskTraction;
extern TaskHandle_t hTaskTourelle;
extern TaskHandle_t hTaskCommunication;
extern TaskHandle_t hTaskAdmin;

// -- Mutex partagé pour le bus SPI0 --
// A PRENDRE (xSemaphoreTake) avant tout SPI.transfer() vers le RC522
// (admin.cpp) OU vers les MCP41100 (Traction.cpp), et RELÂCHER juste après.
// Sans ça, TaskTraction et TaskAdmin peuvent se marcher dessus sur le bus
// et corrompre aussi bien les commandes moteur que la lecture des UID.
// (À câbler dans Traction.cpp / admin.cpp à l'étape suivante.)
extern SemaphoreHandle_t spiMutex;

// -- Mutex pour l'état partagé entre TaskSafety et TaskTraction/TaskTourelle
// (failsafe actif, pourcentage batterie, facteur de bridage) --
extern SemaphoreHandle_t stateMutex;

// -- Mutex pour protéger les écritures concurrentes sur Serial et
// BT_SERIAL (Serial1) entre TaskSafety (alertes batterie/courant) et
// TaskCommunication (télémétrie, réponses aux commandes) --
extern SemaphoreHandle_t serialMutex;

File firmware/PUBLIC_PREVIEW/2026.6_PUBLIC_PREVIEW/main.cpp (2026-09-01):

// =============================================================================================
// Programme Projet Tank Terminale - Spé SI
// Version : 2026.6_PUBLIC_PREVIEW
// Carte : Arduino Mega 2560
// Baudrate : 115200
// Last Build : 01.09.2026 => SUCCESS
// Last Board upload : 01.09.2026 => SUCCESS
//
// ATTENTION : Ce programme à été compilé avec l'outil PlatformIO et
//             contient plusieurs fichiers. Assurez vous d'utiliser
//             PlatformIO ou tout autre logiciel simmilaire pour
//             build le code. 
//
// Pour build le code, configurez PlatformIO, puis dans le sous
// dossier /src/, coller l'ensemble des fichiers : 
//
// - Config.h
// - ISR.cpp
// - ISR.h
// - main.cpp
// - Systeme.cpp
// - Systeme.h
// - Tourelle.cpp
// - Tourelle.h
// - Traction.cpp
// - Traction.h
// - communication.cpp   (fusion de bluetooth.cpp + test.cpp)
// - communication.h     (fusion de bluetooth.h + test.h)
//
// Puis entrez le raccourci "Ctrl + Alt + B" pour build le projet.
// Si tout ce passe bien, une mention [SUCCESS] devrait apparaître.
// =============================================================================================


#include <Arduino.h>  // Librairie PlatformIO

#include "Config.h"   
#include "Systeme.h"  
#include "Traction.h"
#include "Tourelle.h"
#include "ISR.h"
#include "communication.h" // FIX : remplace bluetooth.h + test.h
#include "batterie.h"
#include "Securite.h"
#include "admin.h" // FIX : verrou NFC pour les commandes de diagnostic

void setup() {
  Serial.begin(115200);
  Serial.println("Startup du firmware Projet Tank Terminale - Version " + String(FIRMWARE_VERSION));
  Serial.println("Last build : " + String(LAST_BUILD_DATE));
  Serial.println("Author : " + String(FIRMWARE_AUTHOR));
  initStatusLED();
  setStatusColor(255, 0, 0);
  delay(500);
  Serial.println("Initialisation des modules...");
  
  setupCommunication(); // FIX : remplace setupBluetooth() + setupTestModule()
  setupBatterie();
  setupAdmin(); // FIX : initialise le lecteur NFC admin

  setStatusColor(0, 0, 255);

  setupSysteme();
  setupTraction();

  pinMode(MDRVCT_FAILSAFE, OUTPUT); // FIX : pinMode manquant avant l'écriture ci-dessous
  digitalWrite(MDRVCT_FAILSAFE, LOW);

  setupTourelle();
  setupRecepteur();

  delay(500);
  setStatusColor(0, 255, 0);
  Serial.println("Initialisation terminee. Firmware pret à l'emploi.");
}

void loop() {
  int mainBatteryPct = getBatteryPercentage(MAIN_BATTERY_PIN);
  RcData rc = getRecepteurData();
  bool failsafeActive = checkFailsafe();

  int speed = 0;
  int steering = 0;

  if (failsafeActive) {
    stopTraction();
    stopTourelle();
    setTractionPowerSwitch(false);
    setStatusColor(255, 255, 0); // Jaune - failsafe actif
  } else {
    setTractionPowerSwitch(true);
    gererAlertesBatterie(mainBatteryPct);

    // -- Application des Limites (Limp Mode batterie x Bride Bluetooth) --
    float safetyFactor = calculerBridageBatterie(mainBatteryPct);
    float userMaxSpeed = getBluetoothSpeedLimit();
    float totalFactor = safetyFactor * userMaxSpeed;

    speed = rcToSpeed(rc.yRaw) * totalFactor;
    steering = rcToSpeed(rc.xRaw) * totalFactor;

    // -- Switchs --
    updateSwitch(rc.swcRaw);

    // -- Contrôle tourelle --
    updateEscPower(rc.vraRaw);
    updateTourelleElevation(rc.turretY);

    int tSpeed = 0;
    if (rc.turretX > 900) {
      tSpeed = rcToSpeed(rc.turretX);
    }
    updateTourelleRotation(tSpeed);
  }

  // updateTraction() gère elle-même le mode diagnostic moteur (bypass volontaire
  // de la radio pour les tests au banc). On l'appelle donc toujours : hors mode
  // diagnostic, speed/steering valent 0 pendant le failsafe donc rien ne bouge ;
  // en mode diagnostic, le test au banc reste utilisable même sans signal radio.
  updateTraction(speed, steering, rc.vrbRaw);

  // Continue de tourner même en failsafe : ventilation/température, télémétrie,
  // et écoute des commandes reçues par Bluetooth ET par le port série USB
  // (utile pour diagnostiquer ou désactiver le mode diagnostic à distance).
  updateCommunication(rc.swdRaw); // FIX : remplace updateBluetoothAndFans() + updateTestModule()

  // Scan non bloquant du lecteur NFC admin (voir admin.cpp pour le détail
  // de la limite matérielle liée à l'absence de ligne IRQ).
  updateAdmin();
}

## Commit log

2026-08-30 Added Config.h for preview 2026.6 in order to have the github repo correctly set up
    [Config.h]
2026-08-30 Add Config.h for Arduino firmware configuration
2026-08-31 Driver & Handler upload - 2026.5PR
2026-09-01 Enhance Config.h with firmware settings and utilities
    Added configuration definitions and utility functions for motors, relays, sensors, and Bluetooth module.
2026-09-02 Added PCB files for PCB
    MDRVCT60A002M-MCP41100-EP-4LAYER
    [MDRVCT60A002M-MCP41100-EP.kicad_pcb, MDRVCT60A002M-MCP41100-EP.kicad_sch, led_status.kicad_sch]
2026-09-02 Add manufacturing files information text
    Added a text file containing zip file information with Gerber and drill files, as well as BOM.
2026-09-02 .gbr, .drl and BOM files upload
2026-09-02 Fichiers de Fabrication pour 8CH-SRD-05VDC-SL-C
2026-09-04 Create Fichiers de Fabrication
2026-09-08 Added Engine Characteristics python script
    Utile pour calculer les caractéristiques du moteur du tank pour un calcul rapide.
2026-09-08 Added System Torque script
    Utile pour calculer la force nécéssaire pour faire avancer le tank en changeant certains paramètres physiques ou environnementaux.
2026-09-08 Delete pcb/8CH-SRD-05VDC-SL-C directory
    -- OBSOLETE PCB --
    [8CH-SRD-05VDC-SL-C.kicad_pcb, 8CH-SRD-05VDC-SL-C.kicad_sch]
